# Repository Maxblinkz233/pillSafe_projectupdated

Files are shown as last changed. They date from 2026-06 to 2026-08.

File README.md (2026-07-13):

# PillSafe

Smart medication dispenser (Raspberry Pi hub) + **React Native** caregiver/patient app.

**KNUST — Department of Computer Engineering | BSc Final Year Project**

| Layer | Location | Role |
|---|---|---|
| Pi backend | [`hardware/`](hardware/) | Face/voice verify, schedules, servos, SMS, Flask API |
| Mobile app | [`src/`](src/) | React Native UI wired to the Pi REST API |
| Demo script | [`DEMO.md`](DEMO.md) | Viva / defense walkthrough |

## Quick start — mobile app

```sh
npm install
npm start
# another terminal:
npm run android   # or: npm run ios
```

1. Join the Pi hotspot **PillSafe-AP** (or same LAN).
2. In the app: **Settings → Device Connection**
   - URL: `http://192.168.4.1:5000`
   - Token: from `hardware/config.yaml` → `api.token`
3. **Test Connection** → pick user → **Save**
4. Use **Home / Schedule / Alerts / Verify** against live hub data.

## Quick start — Raspberry Pi hub

Follow the full guide in [`hardware/README.md`](hardware/README.md).

```sh
cd hardware
python3 main.py
# dry-run TAKEN + MISSED for UI proof:
python3 scripts/dry_run_demo.py --db-only
```

## Architecture (app ↔ hub)

- App stores API URL + Bearer token in AsyncStorage.
- **Verify Now** → `POST /dispense/request` with `user_id`, optional `schedule_id`, `auth_mode` (`face` \| `voice`).
- Home / Schedule / Alerts load `/schedules`, `/adherence`, `/notifications`, `/health`.

## Docs

- [Hardware README](hardware/README.md) — wiring, deploy, API reference
- [DEMO.md](DEMO.md) — live demo checklist (taken + missed dose)

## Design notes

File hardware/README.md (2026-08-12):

# PillSafe — Smart Pill Dispenser with Facial Recognition

A Raspberry Pi 5-based smart medication dispensing system that uses facial recognition (FaceNet embeddings), IR-confirmed dispensing, and GSM SMS alerts (SIM800C UART) to ensure safe, verified, and logged medication delivery.

**KNUST — Department of Computer Engineering | BSc Final Year Project**
**Authors:** Boison, Simeon A.A. | Donkor, Maxwell J.
**Supervisor:** Dr Bright Yeboah-Akowuah

---

## Project Structure

```
pillsafe/
│
├── main.py                        # Entry point — initialises and runs everything
├── config.yaml                    # Central configuration (all tuneable parameters)
├── requirements.txt               # Python dependencies
│
├── core/                          # Facial recognition pipeline
│   ├── camera.py                  # Pi Camera v2 capture (Picamera2)
│   ├── detector.py                # Haar Cascade face detection + preprocessing
│   ├── facenet_recogniser.py      # FaceNet embedding-based recognition
│   └── decision.py                # Orchestrates detection → FaceNet recognition
│
├── hardware/                      # Physical component interfaces
│   ├── gpio_compat.py             # Pi 5 lgpio → RPi.GPIO → simulation
│   ├── dispenser.py               # 6× MG996R servos × 9 slots (no gate)
│   ├── ir_sensor.py               # FC-51 IR sensors (pill detect + pickup)
│   ├── buzzer.py                  # 5V active buzzer for audio feedback
│   ├── rtc.py                     # DS3231 RTC via I2C
│   └── gsm.py                     # SIM800C SMS via Pi UART (/dev/serial0)
│
├── scheduler/                     # Time-based dispensing triggers
│   └── schedule_controller.py     # RTC polling + DispenseEvent generation
│
├── database/                      # SQLite data layer
│   ├── schema.sql                 # Tables (Users, Schedules, Inventory, AdherenceLog, Notifications)
│   └── db_manager.py              # Thread-safe CRUD helpers
│
├── api/                           # Flask REST API for mobile app
│   └── routes.py                  # All endpoints (users, schedules, adherence, health)
│
├── alerts/                        # SMS notification service
│   └── alert_service.py           # Background thread monitoring missed-dose events
│
├── enrollment/                    # User facial enrolment
│   └── enrol_user.py              # Sample capture + model retraining (CLI + API)
│
├── utils/                         # Shared utilities
│   ├── config.py                  # YAML config loader with dot-notation access
│   └── logger.py                  # Project-wide logging setup
│
├── data/                          # Runtime data (auto-created)
│   ├── dataset/                   # Facial samples and embeddings: dataset/{user_id}/
│   │                              # embeddings.npy, embeddings_metadata.txt
│   ├── pillsafe.db                # SQLite database
│   └── pillsafe.log               # Application log
│
└── services/
    └── pillsafe.service           # systemd unit file for auto-start on boot
```

---

## Hardware Wiring Guide

> **Full circuit (every wire, resistor, capacitor):** [`docs/WIRING_GUIDE.md`](docs/WIRING_GUIDE.md)  
> **BOM:** [`docs/bom.csv`](docs/bom.csv) · **Net checklist:** [`docs/fritzing_connections.csv`](docs/fritzing_connections.csv)

### GPIO Pin Assignment (BCM Numbering)

| Component | Signal | GPIO (BCM) | Physical Pin | Notes |
|---|---|---|---|---|
| Servo — compartment 0 | PWM | GPIO 12 | Pin 32 | One servo per compartment |
| Servo — compartment 1 | PWM | GPIO 13 | Pin 33 | |
| Servo — compartment 2 | PWM | GPIO 16 | Pin 36 | |
| Servo — compartment 3 | PWM | GPIO 17 | Pin 11 | |
| Servo — compartment 4 | PWM | GPIO 26 | Pin 37 | |
| Servo — compartment 5 | PWM | GPIO 27 | Pin 13 | |
| Servos | VCC | — | External 5V  | MG996R; ≥5–6 A; common GND  |
| Servos | GND | — | GND | Common ground with Pi |
| FC-51 IR (pill det) | OUT | GPIO 23 | Pin 16 | At discharge chute |
| FC-51 IR (pickup) | OUT | GPIO 24 | Pin 18 | At delivery tray |
| FC-51 IR sensors | VCC | — | Pin 1 (3.3V) | Both sensors |
| FC-51 IR sensors | GND | — | Pin 9 | Both sensors |
| Active Buzzer (5V)  | Signal | GPIO 25 | Pin 22 | |
| Active Buzzer (5V)  | VCC | — | Pin 2/4 (5V) | Not 3.3V |
| Active Buzzer | GND | — | Pin 20 | |
| DS3231 RTC | SDA | GPIO 2 | Pin 3 | I2C data (fixed) |
| DS3231 RTC | SCL | GPIO 3 | Pin 5 | I2C clock (fixed) |
| DS3231 RTC | VCC | — | Pin 1 (3.3V) | |
| DS3231 RTC | GND | — | Pin 14 | |
| Pi Camera | CSI | — | CSI port | Ribbon to Pi 5 camera port  |
| SIM800C GSM | TX | GPIO 15 RX | Pin 10 | 3.3V TTL UART |
| SIM800C GSM | RX | GPIO 14 TX | Pin 8 | 3.3V TTL UART |
| SIM800C GSM | VCC | — | — | 3.7–4.2V LiPo (separate) |
| SIM800C GSM | GND | — | Common GND | Share ground with Pi |

### Wiring Diagram (Text)

```
Raspberry Pi 5 GPIO Header (40-pin) — signal pins in BCM numbering
══════════════════════════════════════════════════════════════════
 Power / Ground
   Pin 1  (3.3V) ─── IR VCC, RTC VCC
   Pin 2/4 (5V)  ─── Buzzer VCC (5V module); servos use EXTERNAL 5V ≥5–6 A
   Pin 6/9/14/20/25/30/34/39 (GND) ─── common ground for ALL modules + servo PSU
 Servos (MG996R 360° — one rotating cylinder per compartment)
   GPIO12 (Pin 32) ─── Compartment 0 servo signal
   GPIO13 (Pin 33) ─── Compartment 1 servo signal
   GPIO16 (Pin 36) ─── Compartment 2 servo signal
   GPIO17 (Pin 11) ─── Compartment 3 servo signal
   GPIO26 (Pin 37) ─── Compartment 4 servo signal
   GPIO27 (Pin 13) ─── Compartment 5 servo signal
 Sensors / feedback
   GPIO23 (Pin 16) ─── IR sensor 1 OUT (discharge chute — drop confirm)
   GPIO24 (Pin 18) ─── IR sensor 2 OUT (delivery base — pickup confirm)
   GPIO25 (Pin 22) ─── Buzzer signal (5V module)
 I2C — DS3231 RTC
   GPIO2  (Pin 3, SDA) ─── DS3231 SDA
   GPIO3  (Pin 5, SCL) ─── DS3231 SCL
 UART — SIM800C (3.3V TTL; Serial Console disabled in raspi-config)
   GPIO14 (Pin 8,  TXD0) ─── SIM800C RX
   GPIO15 (Pin 10, RXD0) ─── SIM800C TX
 Voice mic — INMP441 I2S (deferred; leave voice.enabled: false)
 Camera
   CSI port ─── Pi Camera ribbon cable
══════════════════════════════════════════════════════════════════
 SIM800C: powered by a separate 3.7–4.2V LiPo; share GND with the Pi.
 POWER NOTE: six MG996R servos need an external 5V ≥5–6 A supply.
 Tie that supply's GND to a Pi GND — do NOT power 6 servos from the Pi.
```

### Important Notes

1. **SIM800C Power**: Separate 3.7–4.2V LiPo (NOT from Pi rails). Peak TX can approach 2 A.
2. **Common Ground**: SIM800C GND must share ground with the Pi for UART.
3. **Serial Port**: Enable hardware serial, disable login shell. Device: `/dev/serial0`.
4. **I2C Setup**: `sudo raspi-config → Interface Options → I2C → Enable`. Verify with `sudo i2cdetect -y 1`.
5. **Camera**: Enable via `sudo raspi-config → Interface Options → Camera → Enable`.
6. **IR Sensor Orientation**: Mount FC-51 at discharge chute and delivery tray.
7. **Voice**: Leave `voice.enabled: false` until INMP441 is fitted. KY-037 is not suitable for MFCC.

---

## Raspberry Pi 5 — Step-by-Step Deployment

Follow these steps in order once you have the hardware. Commands assume
Raspberry Pi OS **Bookworm 64-bit** and the default username `pi`. If your
username is different, substitute it everywhere (and in
`services/pillsafe.service`). The guide installs into `/home/pi/pillsafe`.

### What you need
- Raspberry Pi 5 + official 27W USB-C PD supply + microSD card (32 GB+)
- Pi Camera (CSI), DS3231 RTC (+ CR2032), 5V active buzzer
- 2× FC-51 IR sensors, 6× MG996R 360° servos + **external 5V ≥5–6 A** supply
- SIM800C GSM on Pi UART (`/dev/serial0`) + 3.7–4.2V LiPo (3.3V TTL)
- (Deferred) INMP441 — keep `voice.enabled: false` until fitted
- Jumper wires / breadboard or a wiring harness

### Step 1 — Flash Raspberry Pi OS
1. Install **Raspberry Pi Imager** on your PC.
2. Choose *Raspberry Pi OS (64-bit)* → your microSD card.
3. Click the gear / *Edit Settings* and pre-configure:
   - Hostname (e.g. `pillsafe`), enable **SSH**, set username `pi` + a password.
   - Wi-Fi SSID/password (so the first boot has internet) and your locale/timezone.
4. Write the card, insert it into the Pi, and boot.

### Step 2 — First boot, update, correct clock
SSH in (`ssh pi@pillsafe.local`) or use a monitor, then:
```bash
sudo apt update && sudo apt full-upgrade -y
timedatectl        # confirm the system time/date is correct (needed to seed the RTC later)
```

### Step 3 — Enable the hardware interfaces
```bash
sudo raspi-config
#  Interface Options → Camera      → Enable
#  Interface Options → I2C         → Enable
#  Interface Options → Serial Port → login shell over serial: NO, serial hardware: YES
```
For the **optional voice mic**, enable I2S by adding this line to
`/boot/firmware/config.txt` (Bookworm path) and reboot:
```bash
echo "dtparam=i2s=on" | sudo tee -a /boot/firmware/config.txt
# Then add the overlay for your INMP441 board per its datasheet, and reboot.
sudo reboot
```

### Step 4 — Install system packages
```bash
sudo apt install -y python3-pip python3-opencv python3-picamera2 \
                    i2c-tools git wget libportaudio2 libsndfile1
```

### Step 5 — Get the PillSafe code onto the Pi
```bash
cd /home/pi
git clone <your-repo-url> pillsafe        # or copy the project folder here via scp
cd /home/pi/pillsafe
```
> If you copy instead of clone, make sure the folder ends up at exactly
> `/home/pi/pillsafe` so it matches the service file in Step 14.

### Step 6 — Install the Python dependencies
```bash
cd /home/pi/pillsafe
pip install -r requirements.txt --break-system-packages

# FaceNet needs a TFLite runtime (ARM64). Try tflite-runtime first;
# fall back to ai-edge-litert if no wheel is available for your Python:
pip install tflite-runtime --break-system-packages || \
pip install ai-edge-litert --break-system-packages
```
> The voice deps (`sounddevice`, `librosa`) are heavy. If you are **not** using
> voice auth, set `voice.enabled: false` in `config.yaml` — the system runs
> fine without them.

### Step 7 — Download the face-recognition model
```bash
bash scripts/download_model.sh          # saves data/models/mobilefacenet.tflite
```

### Step 8 — Wire the hardware and verify each part
Wire everything per the **Hardware Wiring Guide** above (mind the servo power
note). Then verify:
```bash
i2cdetect -y 1          # DS3231 should appear at address 0x68
ls -l /dev/serial0     # SIM800C UART (serial HW on, console off)
libcamera-hello -t 2000 # camera preview (or 'rpicam-hello' on newer OS)
arecord -l              # (voice only) the INMP441 should be listed
```

### Step 9 — Configure `config.yaml`
Edit `config.yaml` and set at minimum:
- `api.token` — replace `CHANGE_ME_ON_FIRST_SETUP` with a strong token (or export
  `PILLSAFE_API_TOKEN` instead; it overrides the file).
- `alerts.serial_port` — `/dev/serial0` for SIM800C UART.
- `servo.pins` — confirm they match how you wired the six MG996R servos.
- `hotspot.ssid` / `hotspot.password` — your access-point name and WPA2 passphrase.
- leave `voice.enabled: false` until INMP441 is fitted.

### Step 10 — Set the DS3231 RTC time
With the system clock correct (Step 2), write it into the RTC once:
```bash
cd /home/pi/pillsafe
python3 -c "from utils.config import load_config; load_config(); \
from hardware.rtc import RealTimeClock; from datetime import datetime; \
print('RTC set:', RealTimeClock().set_time(datetime.now()))"
```
The DS3231's backup cell keeps time across power loss, so schedules fire
correctly even offline.

### Step 11 — (Optional) Turn the Pi into a Wi-Fi hotspot
So a caregiver's phone can connect directly with no router:
```bash
sudo bash services/setup_hotspot.sh
# Phone connects to SSID 'PillSafe-AP'; the API is then at http://192.168.4.1:5000
# To undo:  sudo bash services/setup_hotspot.sh --disable
```

### Step 12 — Enrol users and stock the slots
Register + capture faces (and voice). For a **headless** Pi use the CLI tool;
if a monitor is attached you can use the live-preview tool instead:
```bash
python3 -m enrollment.enrol_user      # headless-friendly
# or, with a screen attached:
python3 enroll_new_user.py            # live camera preview + progress bar
```
Then load the initial pill counts per slot (optional but enables low-stock
alerts) via the API — see Step 15, or POST to `/inventory`.

### Step 13 — Test run (foreground)
```bash
cd /home/pi/pillsafe
python3 main.py
```
Watch the log. In another terminal, confirm the API answers:
```bash
curl http://localhost:5000/health
```
Press `Ctrl+C` to stop once it looks healthy.

### Step 14 — Install as a boot service (auto-start)
```bash
sudo cp services/pillsafe.service /etc/systemd/system/
sudo systemctl daemon-reload
sudo systemctl enable pillsafe      # start automatically on every boot
sudo systemctl start pillsafe
sudo systemctl status pillsafe      # should show 'active (running)'
journalctl -u pillsafe -f           # live logs
```
> If your username isn't `pi`, edit `User=` and the paths in
> `/etc/systemd/system/pillsafe.service`, then `daemon-reload` and restart.

### Step 15 — Auto-start Expo Metro on boot (optional)

If the Pi also hosts the Expo dev server (phone loads the app from the Pi via
Expo Go), install Node **18+** once, copy `pillsafe-expo/` to the Pi, then:

```bash
# One-time: Node 18+ on Bookworm (example — pick your preferred method)
curl -fsSL https://deb.nodesource.com/setup_20.x | sudo -E bash -
sudo apt-get install -y nodejs

# Sync pillsafe-expo to /home/boison08/Documents/pillSafe_projectupdated/pillsafe-expo
cd /home/boison08/Documents/pillSafe_projectupdated/hardware
bash scripts/install_pillsafe_expo_service.sh
```

After reboot both services should be up:

```bash
systemctl is-active pillsafe pillsafe-expo
tail -n 30 data/pillsafe_expo_stdout.log   # QR / exp:// URL appears here
```

On the phone: connect to **PillSafe-AP** (or the same Wi‑Fi), open **Expo Go**,
and enter `exp://10.42.0.1:8081` (hotspot) or `exp://<pi-lan-ip>:8081`.

## Network modes (hotspot ↔ Wi‑Fi from the app)

The Device Connection screen can switch the Pi between **PillSafe-AP** and a
known Wi‑Fi network (no API URL field for end users).

Hub APIs (Bearer auth):

- `GET /network/status`
- `POST /network/hotspot`
- `POST /network/wifi` body `{ "ssid", "password" }`

On the Pi, allow the service user to run `nmcli` without a password:

```bash
sudo bash /home/boison08/Documents/pillSafe_projectupdated/hardware/scripts/install_nmcli_sudoers.sh
sudo systemctl restart pillsafe
```

While on PillSafe-AP the phone uses `http://10.42.0.1:5000` automatically.
After joining home Wi‑Fi, join that same network on the phone and tap **Test Connection**.

## SMS path (Africa’s Talking primary → GSM → phone fallback)

1. Hub calls **Africa’s Talking** REST over HTTPS (credentials in `config.yaml` → `alerts.africas_talking`). Use a **live** username + API key and `sandbox: false` for real caregiver handsets. Sandbox only shows messages in the [AT Simulator](https://simulator.africastalking.com:1517/).
2. If AT fails (missing key, HTTP error, rejected number), hub tries **SIM800L/C** over `/dev/serial0`.
3. If both fail, the hub inserts **`PENDING_PHONE_SMS`** with JSON `{ "to", "body", "reason" }`.
4. The React Native app poller (while connected) sends via phone Africa’s Talking ([`src/config/africasTalking.js`](../src/config/africasTalking.js)) and marks the notification read.

End users only set the caregiver phone (`+233…`). Developers put AT keys in hub `config.yaml` (and optionally the phone config for the last-resort path).

### Deploy SMS after code pull

```bash
# On the Pi — edit live credentials in config.yaml first:
#   alerts.africas_talking.username / api_key, sandbox: false
sudo systemctl restart pillsafe
journalctl -u pillsafe -f
# Expect: "Alert service started (primary=africas_talking, at_configured=True, ...)"
# On a dose event: "Africa's Talking SMS to +233…: Success" (before any pillsafe.gsm line)
```

Pi must have outbound internet (phone hotspot with mobile data, or LAN).

### Step 15 — Connect the mobile app
1. Connect the phone to the Pi's Wi-Fi (`PillSafe-AP`) or the same LAN.
2. Open the **React Native** PillSafe app → **Settings → Device Connection**.
3. Set the API base URL (`http://192.168.4.1:5000` for the hotspot) and the Bearer token from Step 9.
4. Hub SMS uses `hardware/config.yaml` Africa’s Talking keys; optional phone fallback keys live in `src/config/africasTalking.js` (developers only — not shown in the app UI).
5. Tap **Test Connection**, select the patient user, then **Save**.
6. Create users/schedules (API or enrolment CLI), then use **Verify → Verify Now** at dose time.

See [`../DEMO.md`](../DEMO.md) for a full viva/demo checklist, and run a dry-run with:

```bash
python3 scripts/dry_run_demo.py --db-only
# or against a live hub:
python3 scripts/dry_run_demo.py --base-url http://192.168.4.1:5000 --token YOUR_TOKEN
```

### Troubleshooting

| Symptom | Check |
|---|---|
| RTC not found | `i2cdetect -y 1` shows nothing at 0x68 → re-check SDA/SCL/power; is I2C enabled? |
| "TFLite model not loaded" | Run Step 7; confirm `data/models/mobilefacenet.tflite` exists |
| Camera errors | `libcamera-hello`; ensure the CSI ribbon is seated and Camera is enabled |
| No SMS on phone | Set **live** `alerts.africas_talking` (`sandbox: false`); Pi needs HTTPS; caregiver is `+233…`. Sandbox → Simulator only. If AT+GSM fail, hub queues `PENDING_PHONE_SMS` — phone needs data + `src/config/africasTalking.js` |
| GSM-only / no AT | `at_configured=False` in startup log → replace `REPLACE_WITH_*` placeholders; check `journalctl` for Africa's Talking HTTP errors |
| Servos jitter / brown-out | External 5V ≥5–6 A for MG996R; share GND; raise `servo.hold_time` if needed |
| Voice disabled at start | Expected while `voice.enabled: false`; else install sounddevice/librosa + INMP441 |
| Service won't start | `journalctl -u pillsafe -e`; verify `User=`/paths in the unit file |
| API returns 401 | Send `Authorization: Bearer <token>` matching `api.token` / `PILLSAFE_API_TOKEN` |

---

## API Reference

All endpoints (except `/health`) require `Authorization: Bearer <token>` header.

| Method | Endpoint | Description |
|---|---|---|
| GET | /health | System status (no auth) |
| GET | /users | List all users |
| POST | /users | Create user (full_name, caregiver_phone, compartment_index) |
| PUT | /users/{id} | Update user |
| DELETE | /users/{id} | Delete user + facial data |
| POST | /users/{id}/enrol | Trigger facial enrolment |
| GET | /schedules | List schedules (?user_id= filter) |
| POST | /schedules | Create schedule (user_id, medication_name, dose_time, [slot_index, dosage, pills_per_dose, repeat_days]) |
| PUT | /schedules/{id} | Update schedule (incl. slot_index, dosage, pills_per_dose, repeat_days) |
| DELETE | /schedules/{id} | Delete schedule |
| GET | /adherence | Get logs (?user_id=&date= filters) |
| POST | /adherence/{id}/ack | Acknowledge a missed-dose event |
| POST | /dispense/request | "Verify Now" — submit user_id, [schedule_id], auth_mode (face/voice) |
| GET | /inventory | List inventory (?compartment_index= filter)|
| POST | /inventory | Set/update a slot's count (compartment_index, slot_index, pill_count, [medication_name, low_threshold]) |
| GET | /inventory/low | List slots at/below their low threshold |
| GET | /notifications | Event feed (?user_id=&unread=true) |
| POST | /notifications/{id}/read | Mark a notification read |
| GET | /voice/challenge | Random voice passphrase to speak |
| GET | /users/{id}/enrol/status | Face + voice enrolment flags |

> `repeat_days` is a CSV of weekday integers (`0`=Mon … `6`=Sun); empty/omitted means every day. `auth_mode` selects face or voice for that dose.

---

## Medication Storage (Compartments & Slots)

- **6 compartments**, each permanently assigned to one patient (`Users.compartment_index`, 0–5).
- Each compartment is a rotating cylinder with **9 angular slots** (~40° apart). A slot holds one medication / scheduled dose (`Schedules.slot_index`, 0–8).
- Each slot can be **inventory-tracked** (`Inventory` table): a pill count with a low-stock threshold that triggers a `LOW_INVENTORY` notification + SMS.

## Dispensing Mechanism (no gate)

Dispensing is **rotation-only**. Each compartment has its own servo. When a dose is due, that compartment's servo rotates so the target slot aligns with the compartment's fixed **drop hole**; the pill falls by **gravity through a delivery tube to the collection base**. The IR sensors confirm the **drop** and the **pickup**.

## Operational Workflow

```
RTC polls every 60s → Schedule match (time + repeat-day)? → REMINDER notif + buzzer → Camera ON
  → App sends "Verify Now" (POST /dispense/request) → FaceNet/voice verify the SCHEDULED patient
    → ACCEPTED: rotate compartment→slot → IR confirm drop → IR confirm pickup
               → Log TAKEN → decrement inventory → DISPENSED notif (+ LOW_INVENTORY if needed)
    → REJECTED: Log REJECTED → REJECTED notif → SMS to caregiver
    → No Verify Now before grace deadline: Log MISSED → MISSED notif → SMS
```

> Set `dispense.require_verify_request: false` in `config.yaml` for fully autonomous, timer-driven verification (no app handshake).

---

## Key Configuration Parameters

| Parameter | Default | Description |
|---|---|---|
| face.confidence_threshold | 60 | FaceNet match score 0–100 = (1−cosine_dist)×100 (higher = stricter) |
| face.distance_threshold | 0.4 | Max cosine distance (= matches confidence 60) |
| face.max_retries | 8 | Verification attempts before lockout |
| face.sample_count | 50 | Images captured during enrolment |
| schedule.grace_period_minutes | 15 | Window before marking dose as MISSED |
| schedule.poll_interval_seconds  | 60 | How often the scheduler checks the RTC |
| dispense.require_verify_request | true | Wait for the app's "Verify Now" before auth |
| alerts.max_sms_per_event | 2 | Maximum SMS alerts per missed dose |
| alerts.retry_interval_minutes | 60 | Wait time before sending 2nd SMS |
| servo.num_compartments | 6 | Number of compartments (one per patient) |
| servo.num_slots | 9 | Angular slots per compartment (~40° each) |
| servo.pins | [12,13,16,17,26,27] | One PWM signal pin per compartment |

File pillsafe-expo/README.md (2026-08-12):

# PillSafe Expo copy

This is an Expo Go-compatible copy of the existing React Native app. The original
app at the repository root remains unchanged.

The copy intentionally targets **Expo SDK 54**, because the SDK 57 version of
Expo Go is still awaiting Apple App Store approval.

## Run on an iPhone from Windows

1. Install **Expo Go** from the iPhone App Store.
2. Connect the iPhone and Windows PC to the same Wi-Fi network.
3. From this folder, run:

   ```sh
   npm install
   npm start
   ```

4. Scan the displayed QR code with the iPhone camera and open it in Expo Go.
5. In PillSafe, open **Settings → Device Connection** and configure the Pi URL
   and API token.

## SMS (hub Africa’s Talking → GSM → phone fallback)

Hub sends caregiver SMS via **Africa’s Talking** first (live keys in Pi
`config.yaml`). If that fails, GSM; if both fail, the hub queues
`PENDING_PHONE_SMS` and this app’s poller sends via Africa’s Talking using
[`src/config/africasTalking.js`](src/config/africasTalking.js) (developers only —
not in the UI). The phone needs internet for that last-resort API call while
still reaching the hub for polling.

During face enrolment and face verification, the app displays the live
Raspberry Pi camera preview. The preview requires the updated Pi backend in this
repository to be running.

For live hub access, the iPhone, PC running Metro, and Raspberry Pi must be
reachable on the same network. If LAN discovery fails, run `npm start -- --tunnel`;
the iPhone and PC then need internet access, while the iPhone must still be able
to reach the Pi API.

## Auto-start Metro on the Raspberry Pi

You can run Expo on the Pi itself so it starts on every boot (no PC needed):

1. Install **Node.js 18+** on the Pi.
2. Copy this `pillsafe-expo/` folder to
   `/home/boison08/Documents/pillSafe_projectupdated/pillsafe-expo`.
3. On the Pi:

   ```sh
   cd /home/boison08/Documents/pillSafe_projectupdated/hardware
   bash scripts/install_pillsafe_expo_service.sh
   ```

4. Reboot and check:

   ```sh
   systemctl is-active pillsafe-expo
   tail -n 30 /home/boison08/Documents/pillSafe_projectupdated/hardware/data/pillsafe_expo_stdout.log
   ```

5. On the phone (Expo Go): connect to PillSafe-AP or the same Wi‑Fi, then open
   `exp://10.42.0.1:8081` (hotspot) or `exp://<pi-ip>:8081`.

The hub (`pillsafe.service`) and Metro (`pillsafe-expo.service`) are separate
units — enable both for a fully self-contained Pi demo.

## Compatibility note

`react-native-vision-camera` was not copied because the app does not import or
use it. Face and voice verification are initiated by the app but performed by
the Raspberry Pi hub, so removing that unused native dependency does not remove
verification functionality.

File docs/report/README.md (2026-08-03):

# PillSafe FYP Report — Word Paste Pack

Implementation of the *Report vs Implementation — Gap Analysis* plan: Word-ready text that patches Chapter 3 and supplies Chapters 4–6 plus Abstract updates.

## Files

| Order | File | Action in Word |
|---:|---|---|
| 0 | [00_ABSTRACT_AND_FRONT_MATTER.md](00_ABSTRACT_AND_FRONT_MATTER.md) | Replace Abstract; fix “Bright”; extend LoF |
| 1 | [03_CHAPTER3_AMENDMENTS.md](03_CHAPTER3_AMENDMENTS.md) | Amend Ch.3 in place (accuracy pass) |
| 2 | [04_CHAPTER4_IMPLEMENTATION.md](04_CHAPTER4_IMPLEMENTATION.md) | Replace stub Ch.4 |
| 3 | [05_CHAPTER5_TESTING.md](05_CHAPTER5_TESTING.md) | Insert Ch.5; fill measured cells |
| 4 | [06_CHAPTER6_CONCLUSION.md](06_CHAPTER6_CONCLUSION.md) | Insert Ch.6 |

## Source of truth in the repo

- `hardware/config.yaml` — pins, continuous servo, buzzer, SIM800C, grace  
- `hardware/docs/WIRING_GUIDE.md`, `bom.csv` — construction  
- `hardware/api/routes.py` — API surface  
- `src/`, `pillsafe-expo/` — React Native / Expo clients  
- `hardware/cad/` — sized blend / gear–pinion work  

## Writing order (done in this pack)

1. Ch.3 accuracy amendments  
2. Ch.4 implementation narrative  
3. Ch.5 testing tables (ready for your trial numbers)  
4. Ch.6 conclusion + Abstract refresh

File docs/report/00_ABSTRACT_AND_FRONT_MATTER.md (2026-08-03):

# PillSafe — Abstract & Front-Matter Updates

Paste these replacements into the Word report. Do **not** leave the February 2026 draft wording for face-only / Flutter / generic Wi-Fi module.

---

## Abstract (replacement)

Medication non-adherence remains a major cause of treatment failure, especially among elderly and chronically ill patients who manage multiple daily doses. Existing electronic pill dispensers often lack strong identity verification, rely on weak alarms, or do not notify caregivers when a dose is missed. This project presents **PillSafe**, a biometric medication-dispensing system that combines a Raspberry Pi 5 hub with a React Native mobile application.

The hub stores prescribed schedules in SQLite, reminds the patient when a dose becomes due (buzzer on the device and an in-app alert), and releases medication only after successful biometric verification. Authentication uses facial recognition (MobileFaceNet TensorFlow Lite with OpenCV Haar detection) and an optional voice-enrolment / verification path via a Voice HAT microphone. Six patient compartments are driven by MG996R continuous-rotation servos; each compartment holds nine angular slots at 40° steps. After a successful verify, the assigned servo advances one slot and gravity delivers the dose; optional IR sensors can confirm drop and pickup. Missed doses after a configurable grace period, repeated verification failures, and related faults generate SMS alerts to a caregiver through a SIM800C module on the Pi UART. The phone app manages device connection, schedules (including AM/PM dosing and edit/delete), live camera preview for enrolment and verify, adherence monitoring, and the Verify Now handshake with the hub.

The system is designed for home and small-clinic use where reliable, identity-gated dispensing and caregiver visibility matter more than cloud-centric pharmacy automation. Implementation, construction, and evaluation are reported in Chapters 4–6.

**Keywords:** medication adherence, facial recognition, voice biometrics, Raspberry Pi 5, React Native, GSM SMS, smart pill dispenser.

---

## Declaration — supervisor name

Correct the declaration block:

- **Wrong:** … supervised by Mr. Bight …
- **Correct:** … supervised by **Mr. Bright** …

(Use the full official supervisor name as required by your department if it differs from “Bright” alone.)

---

## Suggested list-of-figures additions (Ch.4–6)

| Fig. | Caption (suggested) |
|---|---|
| 4.1 | System stack: Pi 5, Voice HAT, camera, servo rail, SIM800C |
| 4.2 | Power domains (Pi PD / servo 5 V / GSM LiPo) with common GND |
| 4.3 | GPIO pin map used by PillSafe |
| 4.4 | Software module map (hub + mobile app) |
| 4.5 | Enrolment flow (face and optional voice) |
| 4.6 | CAD: compartment outer dimensions (~Ø200 × 21.67 mm) |
| 4.7 | Layer gear (~72T) and matched 16T pinion mesh |
| 5.1–5.n | Face / voice / dispense / reminder / missed-dose result charts |
| 6.1 | Objectives vs achievements summary |

---

## How to use this folder

| File | Purpose |
|---|---|
| `03_CHAPTER3_AMENDMENTS.md` | Accuracy patch for Methodology & Design |
| `04_CHAPTER4_IMPLEMENTATION.md` | New Chapter 4 body |
| `05_CHAPTER5_TESTING.md` | New Chapter 5 body + result tables |
| `06_CHAPTER6_CONCLUSION.md` | New Chapter 6 + future work |
| `00_ABSTRACT_AND_FRONT_MATTER.md` | This file |

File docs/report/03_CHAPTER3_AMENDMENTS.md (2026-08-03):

# Chapter 3 — Methodology & Design: Accuracy Amendments

Replace or amend the corresponding subsections in the existing Chapter 3 so the design chapter matches the **implemented** system. Strike-through / delete obsolete claims (Flutter, Pi 4B as sole target, SG90, 60° six-compartment step, PCA9685 as required PWM driver, SIM800L USB-serial as the only GSM path, face-only auth).

---

## 3.x System overview (amended narrative)

PillSafe consists of:

1. **Hub** — Raspberry **Pi 5** running Python (Flask REST API, schedule controller, face/voice pipelines, dispenser drivers, SQLite).
2. **Mobile client** — **React Native** application (`src/`); an **Expo Go** variant (`pillsafe-expo/`) supports camera-less UI preview during development.
3. **Mechanics** — six patient compartments, each with a rotating cylinder of **nine slots at 40°**, driven by one **MG996R** continuous-rotation servo; gravity drop to a collection point; optional IR confirmation.
4. **Alerts** — on-device **buzzer** when a dose becomes due; **SMS** via **SIM800C** on Pi UART for missed doses, verification failures, and selected faults; in-app reminder poller (“Time Is Up”) on the phone.

Local Wi-Fi (typically the Pi hotspot or LAN) carries HTTPS/HTTP REST between app and hub. No cloud dependency is required for core dispense and adherence logging.

---

## 3.x Hardware platform (replace Pi 4B-centric wording)

| Item | Design choice |
|---|---|
| SBC | **Raspberry Pi 5** (64-bit Raspberry Pi OS) |
| GPIO stack | Compatibility layer: **lgpio** preferred → **RPi.GPIO** fallback → **simulation** for dry-run (`gpio_compat`) |
| Camera | CSI Pi Camera (MJPEG stream + JPEG snapshot to the phone) |
| Voice (optional) | Voice HAT / I2S mic path; sample-rate handling in hub voice modules |
| RTC | DS3231 on I2C for reliable wall-clock scheduling |
| Servos | **6 × MG996R**, continuous / 360° style, external 5 V ≥5–6 A supply, **common GND with Pi** |
| Servo PWM pins | BCM **12, 13, 22, 17, 26, 27** (GPIO **16 avoided** — Voice HAT conflict) |
| IR | FC-51 pair on BCM **23** (drop) and **24** (pickup); may be non-mandatory during bring-up |
| Buzzer | Active module on BCM **25**; **dose-due reminder only** (stopped before dispense verify) |
| GSM | **SIM800C**, UART **`/dev/serial0`** @ 9600; TX→GPIO15(RX), RX→GPIO14(TX); **separate LiPo** power |

**Remove / correct:**

- Claims that the sole controller is Raspberry **Pi 4B**.
- **PCA9685** as a required PWM expander for this pin map (direct GPIO PWM / software PWM as configured).
- Servo on **GPIO18** as the primary dispense pin.
- **SG90** as the project servo.
- **SIM800L over USB-serial** as the documented production path (SIM800C UART is the configured path).

---

## 3.x Dispensing mechanism (replace 60° / single-servo carousel language)

### Compartment geometry

- **Six** patient compartments (one servo each).
- Each cylinder: **nine** dose slots.
- Angular step: **40°** per slot (9 × 40° = 360°).
- Delivery: **gravity drop** after rotation; no motorised gate in the baseline design.

### Actuation model

Continuous-rotation MG996R units are driven with a **timed duty** around a calibrated **neutral** pulse (≈7.5% at 50 Hz), not absolute 0–360° positional PWM.

Key parameters (see `hardware/config.yaml`):

- `mode: continuous`
- `angle_per_slot: 40`
- `neutral_duty`, `run_duty_offset`, `degrees_per_second` — tuned so one command advances ≈ one slot
- `use_slot_indexing: true` — software tracks slot index per compartment

**Remove:** formulas and text that treat the machine as **one** SG90 advancing a shared carousel by **60°** between six compartments.

### Mechanical / CAD design intent

CAD under `hardware/cad/` sizes the stack around a compartment envelope on the order of **~Ø200 mm × ~21.67 mm** height for reference layers. Layer gear work targets approximately **72 teeth** on the large gear with a matched **16-tooth pinion** (pitch radius / centre-distance chosen for mesh with small clearance). Report figures should cite the sized Blender models rather than a generic “carousel sketch.”

---

## 3.x Authentication design (amend face-only sections)

### Face (primary)

- OpenCV Haar cascade for detection.
- **MobileFaceNet** TFLite embeddings; cosine-distance / confidence thresholds from config.
- Enrolment stores samples under the hub dataset path; verify runs on the hub after the app issues Verify Now (when `require_verify_request` is true).
- Live **camera stream** and **snapshot** endpoints support phone-side preview during enrol/verify.

### Voice (optional secondary path)

- Challenge phrase / enrolment APIs (`/voice/challenge`, `/users/<id>/enrol/voice`).
- Verification integrated into the dispense verify path when voice is enabled and enrolled.
- Document Voice HAT sample-rate constraints and that voice may be disabled in config until hardware is fitted.

**Amend** any statement that authentication is **face only**.

---

## 3.x Mobile application (replace Flutter)

| Aspect | Implementation |
|---|---|
| Framework | **React Native** (TypeScript/JavaScript under `src/`) |
| Demo / preview | **Expo Go** project `pillsafe-expo/` for UI without full native camera stack |
| Connection | Device IP + shared API token (`pillsafe` default; change for deployment) |
| Schedules | Create with **AM/PM** dose picker; **long-press** to edit/delete (subject to “already TAKEN today” rules) |
| Reminders | Poller detects due doses; **“Time Is Up”** alert; navigate to Verify via nested `MainApp` → `Verify` |
| Monitor | Missed / adherence aligned with schedule + grace logic used on Home |
| Verify | Disabled when there is no actionable dose; handshake `POST /dispense/request` then hub auth |

**Remove** Flutter/Dart as the implemented client stack.

---

## 3.x Scheduling, reminders, and alerts (amend)

1. Schedules stored in SQLite; hub polls on `poll_interval_seconds` (default 15 s).
2. When a dose becomes due: **buzzer** runs the dose-ready pattern (~45–60 s configurable); buzzer **stops** before dispense authentication so it does not interfere with mic/camera UX.
3. App reminder poller surfaces the same due window; user taps **Verify Now**.
4. Hub authenticates (face ± voice), advances the correct compartment one slot, logs **TAKEN** (IR optional).
5. If grace period expires without success: log **MISSED**, notify caregiver by **SMS** (and in-app notifications where applicable).
6. Repeated failed verify sets can trigger SMS and temporary lockout per face config thresholds.

**Amend** text that treats the buzzer as a generic “start of face verify” alarm only, without the dose-due / stop-before-dispense policy.

---

## 3.x Software architecture sketch (update)

```
React Native app  ──REST──►  Flask API (routes.py)
                                │
                                ├── Face / Voice / Camera
                                ├── ScheduleController
                                ├── Dispenser (6× continuous servo + IR)
                                ├── Buzzer (dose-due)
                                ├── GSM (SIM800C UART)
                                └── SQLite (users, schedules, adherence, …)
```

Central tuning lives in `hardware/config.yaml` (NFR-style single config file).

---

## 3.x API surface (expand the short sketch)

Representative endpoints (all behind shared token / auth as implemented):

| Area | Methods (examples) |
|---|---|
| Health | `GET /health` |
| Camera | `GET /camera/snapshot`, `GET /camera/stream`, `POST /camera/preview/stop` |
| Users | CRUD + `POST .../enrol`, `.../enrol/voice`, `.../enrol/status` |
| Dispense | `POST /dispense/request`, `POST /dispense/verify` |
| Schedules | `GET/POST /schedules`, `PUT/DELETE /schedules/<id>` |
| Adherence | `GET /adherence`, ack endpoints |
| Inventory / notifications | as implemented |
| Test | `POST /alerts/dose-due-test` |

---

## Checklist for the writer (Ch.3 pass)

- [ ] Pi **5** + `gpio_compat` mentioned  
- [ ] React Native (+ Expo Go if used in demo)  
- [ ] Face **and** optional voice  
- [ ] 6 × MG996R, 9 × 40°, continuous timed steps  
- [ ] Pins [12, 13, 22, 17, 26, 27]; no GPIO16 for servo  
- [ ] SIM800C UART `/dev/serial0`  
- [ ] Buzzer = dose-due only; stop before dispense  
- [ ] Flutter / SG90 / 60° / GPIO18-primary / PCA9685-required / face-only removed or clearly marked superseded

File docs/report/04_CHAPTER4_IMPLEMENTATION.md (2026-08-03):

# Chapter 4 — Implementation and Construction

Word-ready body text. Insert figures from photos of your build and from `hardware/cad/` / `hardware/docs/`.

---

## 4.1 Introduction

This chapter describes how the PillSafe design was realised in hardware, embedded software, and the mobile client. It covers the bill of materials and wiring practice, the organisation of hub and app modules, biometric enrolment procedures, and the mechanical CAD decisions that support the six-compartment, nine-slot dispenser.

---

## 4.2 Bill of materials and wiring

### 4.2.1 Bill of materials (summary)

The authoritative parts list is maintained in `hardware/docs/bom.csv`. Major items include:

| Category | Component | Qty | Role |
|---|---|-----|---|
| Controller | Raspberry Pi 5 | 1 | Hub computer |
| Power (Pi) | Official 27 W USB-C PD | 1 | Pi only |
| Storage | microSD 32 GB+ | 1 | Raspberry Pi OS |
| Vision | Pi Camera Module + CSI ribbon | 1 | Enrol / verify |
| Dispensing | MG996R continuous / 360° servo | 6 | One per compartment |
| Dispensing | External 5 V ≥5–6 A PSU | 1 | Servo VCC only |
| Sensors | FC-51 IR modules | 2 | Drop + pickup |
| Feedback | Active 5 V buzzer | 1 | Dose-due reminder |
| Time | DS3231 + CR2032 | 1 | RTC |
| GSM | SIM800C + LiPo + SIM + antenna | 1 set | Caregiver SMS |
| Voice (optional) | Voice HAT / I2S mic | 0–1 | Voice enrol/verify |
| Passives | 1000 µF rail caps, optional PWM series R, TX divider if needed | as BOM | Electrical safety |

Full notes and config cross-references remain in the BOM CSV.

### 4.2.2 Power architecture

Three **isolated positive rails** share a **single common ground**:

1. Pi — official USB-C PD only.  
2. Servos — external 5 V high-current supply (never the Pi 5 V pins for six MG996R).  
3. SIM800C — 3.7–4.2 V LiPo (GSM TX peaks must not collapse the Pi rail).

A bulk electrolytic capacitor (e.g. 1000 µF / 16 V) across the servo rail absorbs stall spikes. Power-up order: wiring complete → GND verified → servo PSU → LiPo → Pi last.

*[Insert Figure 4.2 — power domains diagram; may reproduce the ASCII/schematic from WIRING_GUIDE.md]*

### 4.2.3 Signal wiring summary

Detailed pin-by-pin instructions are in `hardware/docs/WIRING_GUIDE.md`, with a net checklist in `fritzing_connections.csv`.

| Function | BCM / interface | Notes |
|---|---|---|
| Servo PWM | 12, 13, 22, 17, 26, 27 | One line per compartment; GPIO 16 reserved / Voice HAT |
| IR drop / pickup | 23 / 24 | 3.3 V logic |
| Buzzer | 25 | VCC from Pi 5 V if module is 5 V active |
| RTC | I2C (SDA/SCL) | DS3231 @ 0x68 |
| GSM | UART `/dev/serial0` | SIM800C TX→15, RX→14; 3.3 V TTL; divider if TX > 3.3 V |
| Camera | CSI | Stream + snapshot via API |
| Voice | Voice HAT / I2S | As fitted; keep `voice.enabled` false until ready |

GPIO access on Pi 5 uses the project compatibility layer (`hardware/gpio_compat.py`) so the same code path can run under lgpio, RPi.GPIO, or simulation for dry-run demos without hardware.

*[Insert Figure 4.3 — annotated 40-pin header map]*

---

## 4.3 Hub software implementation

### 4.3.1 Module map

| Module / area | Responsibility |
|---|---|
| `main.py` | Process entry, wiring of controllers, API start |
| `config.yaml` | Single source of tuneable thresholds and pins |
| `gpio_compat.py` | Pi 5–friendly GPIO backends |
| `core/` / face pipeline | Haar + MobileFaceNet TFLite match |
| Voice modules | Challenge, enrol, verify (when enabled) |
| Camera helpers | Shared camera for MJPEG / JPEG endpoints |
| `dispenser.py` | Continuous servo slot steps, IR wait policy |
| Schedule controller | Due / grace / MISSED / REMINDER coordination |
| `gsm.py` | SIM800C AT commands over UART |
| Buzzer driver | Dose-due pattern; stopped before dispense |
| `api/routes.py` | Flask REST surface for the phone |
| SQLite DB layer | Users, schedules, adherence, inventory, notifications |

*[Insert Figure 4.4 — module block diagram]*

### 4.3.2 Dispenser control

With `servo.mode: continuous`, a dispense command does not seek an absolute PWM angle. Instead it:

1. Selects the compartment pin for the patient / schedule.  
2. Runs the servo away from `neutral_duty` for a duration derived from `angle_per_slot` and `degrees_per_second`.  
3. Returns to neutral and settles.  
4. Advances the software slot index.  
5. Optionally waits for IR confirmation (`ir_sensors.required`); during bring-up this may be false so TAKEN can still be logged after a successful verify and move.

Calibration consists of adjusting `degrees_per_second` (and duty offsets) until one step visually matches ≈40° on the printed cylinder.

### 4.3.3 Scheduling and reminder policy

- Schedules and adherence events persist in SQLite.  
- The hub polls on a short interval (default 15 s).  
- On dose-due: buzzer pattern (~50 s typical); app may call `POST /alerts/dose-due-test` during lab tests.  
- When `require_verify_request` is true, the hub waits for `POST /dispense/request` from the app before running authentication.  
- After success, dispense runs and adherence is updated; after grace expiry, MISSED + SMS paths fire.

### 4.3.4 REST API (implemented)

The Flask service binds `0.0.0.0:5000` by default with a shared token. Implemented groups include health, camera snapshot/stream, user CRUD and enrolment, voice challenge/enrol, dispense request/verify, schedule CRUD, adherence, inventory, notifications, and dose-due test. This is a full operational surface, not a stub.

---

## 4.4 Mobile application implementation

### 4.4.1 Stack

The production-facing client is **React Native** under `src/`. A parallel **Expo Go** project (`pillsafe-expo/`) allows rapid UI iteration when native camera tooling is not required.

### 4.4.2 Key screens and behaviours

| Feature | Behaviour |
|---|---|
| Device connection | Hub IP + API token; health check |
| Home / dashboard | Today’s doses, adherence-oriented stats |
| Schedules | Create with AM/PM picker; long-press edit/delete; block edit after TAKEN today where enforced |
| Reminders | Background-style poller while app usable; “Time Is Up”; deep link to Verify via nested navigation `MainApp` → `Verify` |
| Verify | Camera preview against hub stream/snapshot; disabled when no actionable dose |
| Monitor | Missed counts aligned with the same schedule + grace logic as Home |
| Enrolment UI | Face (and voice when enabled) against hub enrol endpoints |

---

## 4.5 Enrolment procedures

### 4.5.1 Face enrolment

1. Create or select the patient user on the hub (app or API).  
2. Ensure camera preview is live (`/camera/stream` or snapshot).  
3. Call face enrol (`POST /users/<id>/enrol`) and capture the configured sample count under good lighting.  
4. Confirm enrol status via `/users/<id>/enrol/status`.  
5. Validate with a dry verify before loading medication.

### 4.5.2 Voice enrolment (optional)

1. Enable voice in config and confirm Voice HAT / mic path.  
2. Fetch challenge text (`GET /voice/challenge`).  
3. Record and submit (`POST /users/<id>/enrol/voice`).  
4. Confirm status; include voice in subsequent `/dispense/verify` trials.

*[Insert Figure 4.5 — enrolment sequence diagram]*

---

## 4.6 Mechanical construction and CAD

### 4.6.1 Compartment stack

Sized Blender models under `hardware/cad/` (e.g. `PillSafe_Design_SIZED.blend` and working copies) define a compartment envelope on the order of:

- Outer diameter ≈ **200 mm**  
- Layer / compartment height ≈ **21.67 mm** (reference layer used for stacking)

Six layers correspond to six patients; each layer’s inner cylinder presents **nine** equal sectors for doses.

### 4.6.2 Drive gear and pinion

Layer gear geometry used in the sized design is approximately **72 teeth** at **5°** tooth spacing on the large ring. A matched **16-tooth** stub pinion was designed so that:

- Pitch radii sum (plus a small clearance, e.g. ~0.2 mm) set centre distance.  
- Tip/root diameters and face width suit FDM print tolerance.  
- Material assignment in CAD distinguishes structural plastic from a steel-look pinion for clarity in figures.

*[Insert Figure 4.6 — compartment dimensions]*  
*[Insert Figure 4.7 — 72T ring vs 16T pinion mesh]*

### 4.6.3 Assembly notes

- Print tolerance on tooth thickness and backlash dominates continuous-servo open-loop accuracy; mechanical calibration and `degrees_per_second` must be co-tuned.  
- Gravity drop path and IR sight lines should be verified before locking the outer shell.  
- Keep servo wiring strain-relieved; PWM lines may use optional series resistors per the wiring guide.

---

## 4.7 Configuration and dry-run practice

All tuneables live in `hardware/config.yaml` (face thresholds, grace period, servo continuous calibration, buzzer timing, GSM port, API token). Unit tests and dry-run / simulation paths for dispenser and database support bring-up without full mechanics. Document the token change and serial console disable (`raspi-config`: serial port on, login shell off) as part of commissioning.

---

## 4.8 Chapter summary

PillSafe was implemented as a Pi 5 hub with continuous MG996R slot indexing, Flask APIs including camera and biometrics, SIM800C UART alerts, and a React Native client with schedule and reminder UX. Mechanical CAD progressed from a generic carousel sketch to sized layers with an explicit gear–pinion pair. The next chapter evaluates these subsystems through structured tests.

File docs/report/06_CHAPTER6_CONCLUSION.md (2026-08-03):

# Chapter 6 — Conclusion and Future Work

Word-ready body. Align the objectives checklist with the wording used in Chapter 1 of your dissertation.

---

## 6.1 Conclusion

This project set out to design and implement **PillSafe**, a biometric, schedule-driven medication dispenser for home and small-clinic use. The realised system centres on a **Raspberry Pi 5** hub and a **React Native** mobile application.

On the hub, prescribed times are stored in SQLite and supervised by a schedule controller. When a dose becomes due, the device issues a **buzzer reminder** and the phone can surface a **“Time Is Up”** alert. Medication is released only after successful biometric checks—**facial recognition** with MobileFaceNet TFLite, with an **optional voice** enrolment/verification path. Dispensing uses **six MG996R** continuous-rotation servos, each advancing a **nine-slot** cylinder in **40°** calibrated steps, with gravity delivery and optional IR confirmation. Caregivers can be notified by **SMS** through a **SIM800C** on the Pi UART when doses are missed or verification fails repeatedly.

Relative to the early design draft, the implementation clarified several engineering choices: Pi 5 GPIO compatibility, continuous rather than absolute positional servo control, per-compartment motors instead of a single SG90 carousel step, UART GSM instead of USB-serial SIM800L as the primary path, and React Native instead of Flutter. Mechanical CAD progressed to sized compartment geometry and a matched **~72T / 16T** gear–pinion pair.

Overall, PillSafe demonstrates a coherent end-to-end pipeline—from schedule and reminder, through identity-gated dispense, to adherence logging and caregiver alert—suitable as a final-year prototype and as a foundation for further clinical hardening.

---

## 6.2 Objectives versus achievements

Adapt row wording to match Chapter 1 exactly.

| # | Objective (from Ch.1) | Status | Evidence |
|---|---|---|---|
| 1 | [e.g. Design a multi-compartment dispenser with identity control] | Achieved / Partially | Ch.3–4; 6×9 mechanism; face (± voice) |
| 2 | [e.g. Implement scheduling and dose reminders] | Achieved / Partially | Schedule controller; buzzer; app poller |
| 3 | [e.g. Notify caregiver on missed / failed access] | Achieved / Partially | SIM800C path; DB MISSED; Ch.5 Table 5.6 |
| 4 | [e.g. Provide a mobile interface for management] | Achieved | React Native: connect, schedules, verify, monitor |
| 5 | [e.g. Evaluate system performance] | Achieved / In progress | Ch.5 tables — fill with campaign data |

Mark any objective that depended on unfinished print validation or live SMS as **partially achieved** and explain briefly.

---

## 6.3 Contributions

1. An integrated **Pi 5** hub with config-driven face, schedule, dispense, buzzer, and GSM modules.  
2. A **continuous-servo slot index** model aligned with a nine-slot / 40° mechanical layout.  
3. A **React Native** client with connection token, AM/PM schedules, edit/delete, reminder UX, and verify handshake.  
4. Optional **voice** enrolment APIs and camera streaming for phone-assisted biometrics.  
5. CAD and wiring documentation (BOM, wiring guide, sized gear/pinion) supporting reproducible construction.

---

## 6.4 Limitations

- Open-loop continuous servos without encoders.  
- Reminder reliability when the mobile OS suspends the app.  
- IR and GSM sometimes optional or simulated during lab bring-up.  
- Prototype enclosure / full six-layer print validation may still be incomplete.  
- Not a certified medical device; no clinical trial was conducted within this FYP scope.

---

## 6.5 Future work

1. **Push notifications** (FCM/APNs) so caregivers and patients are alerted when the app is backgrounded.  
2. **Full six-layer print and soak test** — multi-day adherence run with all compartments loaded.  
3. **Closed-loop slot indexing** — magnetic encoder or limit switch per cylinder to eliminate drift.  
4. **Optional cloud sync** — encrypted backup of schedules and adherence for multi-caregiver access.  
5. **Clinical usability study** — elderly users and caregivers; measure adherence lift vs manual organisers.  
6. Hardening: rotated API tokens, TLS on the local API, tamper detection on the enclosure.

---

## 6.6 Final remarks

PillSafe shows that commodity SBC hardware, careful GPIO and power design, and a focused mobile client can deliver identity-gated dispensing with caregiver visibility. Completing the measured test campaign in Chapter 5 and refreshing the abstract to match this architecture leaves the dissertation aligned with the working prototype.

---

## After inserting Chapters 4–6

1. Replace the Abstract using `00_ABSTRACT_AND_FRONT_MATTER.md`.  
2. Fix supervisor spelling (**Bright**).  
3. Regenerate **Table of Contents**, **List of Figures**, and **List of Tables**.  
4. Add new references if you cite MobileFaceNet, Expo, lgpio, SIM800C datasheets, etc., not already in Ch.2.  
5. Delete the duplicated stub “4.1 Introduction” that merely recopied Chapter 3’s opening from the February draft.

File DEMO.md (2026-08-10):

# PillSafe — Demo Script (defense / viva)

Use this checklist for a live demonstration. Time budget: ~10–15 minutes.

## Before you start (5 min)

1. Power the Raspberry Pi and external 5 V servo supply (common GND).
2. Confirm service is running:
   ```bash
   sudo systemctl status pillsafe
   # or: cd /home/pi/pillsafe/hardware && python3 main.py
   ```
3. Phone joins **PillSafe-AP** (or same LAN as the Pi).
4. Open the React Native app → **Settings → Device Connection**:
   - API URL: `http://192.168.4.1:5000` (hotspot) or `http://<pi-ip>:5000`
   - Token: value from `hardware/config.yaml` → `api.token`
   - Tap **Test Connection** → select the demo user → **Save**
   - (Developers) Hub SMS: live Africa’s Talking keys in `hardware/config.yaml` → `alerts.africas_talking`. Phone last-resort key: `src/config/africasTalking.js` (not in the UI)
5. Optional dry-run seed (dev machine or Pi):
   ```bash
   cd hardware
   python3 scripts/dry_run_demo.py --db-only
   ```

## Demo A — Successful dose (TAKEN)

| Step | Action | Expected |
|---|---|---|
| 1 | Show **Home** | Live schedules, device Online, stats from API |
| 2 | Wait for RTC schedule match (or create a schedule for *now* + 1 min) | Buzzer `dose_ready`, REMINDER notification |
| 3 | Open **Verify** → **Verify Now (Face)** | App POSTs `/dispense/request` |
| 4 | Enrolled patient faces Pi camera | FaceNet ACCEPT → servo rotates → IR drop → pickup |
| 5 | Show **Home / Alerts** | DISPENSED notification, adherence TAKEN |

**Voice variant:** Verify → Use Voice Instead → speak passphrase into hub mic.

## Demo B — Missed dose (MISSED + SMS)

| Step | Action | Expected |
|---|---|---|
| 1 | Trigger a schedule; do **not** press Verify Now | Grace period (default 15 min — shorten in `config.yaml` for demos) |
| 2 | Let grace expire | Adherence MISSED, MISSED notification |
| 3 | Caregiver phone | SMS via Africa’s Talking first, then SIM800L if AT fails |
| 4 | Show **Alerts** filter **Missed** | Unread MISSED card |

**Shortcut for UI-only proof** (no waiting):

```bash
python3 scripts/dry_run_demo.py --db-only
```

Then refresh Home / Alerts on the phone.

## Demo C — Rejected identity (optional)

1. Start a dose for patient A.
2. Have patient B (or an unenrolled face) attempt verification.
3. After max retries → REJECTED log + SMS + Alerts card.

## Talking points

- Identity is bound to the **scheduled** user (not any enrolled face).
- App does not capture biometrics; the **Pi camera / mic** does.
- Offline-capable: hotspot + SQLite + DS3231 RTC.
- Dual auth: face **or** voice (`auth_mode` on `/dispense/request`).

## Failures & recovery

| Symptom | Fix |
|---|-----|
| App offline / connection error | Device Connection URL/token; same Wi-Fi; `curl http://PI:5000/health` |
| 401 Invalid token | Match `api.token` / `PILLSAFE_API_TOKEN` |
| Verify accepted but no dispense | Check Pi logs: face reject, IR timeout, servo power |
| No SMS | Live AT keys in `config.yaml` (`sandbox: false`), Pi HTTPS; else SIM800L LiPo + `alerts.serial_port`; else `PENDING_PHONE_SMS` + phone data |

## Backup (if hardware fails on the day)

1. Run `python3 scripts/dry_run_demo.py --db-only` and show live app screens.
2. Play a pre-recorded video of a successful physical dispense.
3. Walk examiners through `hardware/main.py` dispense flow and `DEMO.md`.

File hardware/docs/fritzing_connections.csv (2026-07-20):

Net | From | From pin/signal | To | To pin/signal | Wire colour (suggested) | Notes
GND | Pi | Pin 6/9/14/20 GND | GND bus | Common | Black | Star ground for all supplies
GND | External 5V PSU | GND | GND bus | Common | Black | Mandatory — share with Pi
GND | LiPo 3.7V | − | GND bus | Common | Black | SIM800C return path
GND | GND bus | Common | Servo 0 | GND | Brown | Repeat for servos 1–5
GND | GND bus | Common | Servo 1 | GND | Brown
GND | GND bus | Common | Servo 2 | GND | Brown
GND | GND bus | Common | Servo 3 | GND | Brown
GND | GND bus | Common | Servo 4 | GND | Brown
GND | GND bus | Common | Servo 5 | GND | Brown
GND | GND bus | Common | DS3231 | GND | Black
GND | GND bus | Common | IR drop | GND | Black | FC-51 chute
GND | GND bus | Common | IR pickup | GND | Black | FC-51 tray
GND | GND bus | Common | Buzzer | GND | Black | 5V active module
GND | GND bus | Common | SIM800C | GND | Black
GND | GND bus | Common | INMP441 | GND | Black | Optional voice
GND | GND bus | Common | Divider R2 | bottom | Black | Only if SIM TX level-shifted
3V3 | Pi | Pin 1 (3.3V) | DS3231 | VCC | Red | Module usually has 4.7k I2C pull-ups
3V3 | Pi | Pin 1 (3.3V) | IR drop | VCC | Red
3V3 | Pi | Pin 1 (3.3V) | IR pickup | VCC | Red
3V3 | Pi | Pin 1 (3.3V) | INMP441 | VDD | Red | Optional; L/R also to GND
5V_PI | Pi | Pin 2 or 4 (5V) | Buzzer | VCC | Red | 5V buzzer only — not servos/GSM
5V_SERVO | External PSU | +5V | Servo 0 | VCC | Red | Do NOT use Pi 5V for 6× MG996R
5V_SERVO | External PSU | +5V | Servo 1 | VCC | Red
5V_SERVO | External PSU | +5V | Servo 2 | VCC | Red
5V_SERVO | External PSU | +5V | Servo 3 | VCC | Red
5V_SERVO | External PSU | +5V | Servo 4 | VCC | Red
5V_SERVO | External PSU | +5V | Servo 5 | VCC | Red
5V_SERVO_CAP | External PSU | +5V | Cap 1000uF 16V | + | Red | Decoupling near servos
5V_SERVO_CAP | GND bus | Common | Cap 1000uF 16V | − | Black
SERVO0_SIG | Pi | GPIO12 Pin32 | R220_0 | in | Orange | Optional series 220–470Ω
SERVO0_SIG | R220_0 | out | Servo 0 | Signal | Orange | Compartment 0
SERVO1_SIG | Pi | GPIO13 Pin33 | R220_1 | in | Orange
SERVO1_SIG | R220_1 | out | Servo 1 | Signal | Orange | Compartment 1
SERVO2_SIG | Pi | GPIO16 Pin36 | R220_2 | in | Orange
SERVO2_SIG | R220_2 | out | Servo 2 | Signal | Orange | Compartment 2
SERVO3_SIG | Pi | GPIO17 Pin11 | R220_3 | in | Orange
SERVO3_SIG | R220_3 | out | Servo 3 | Signal | Orange | Compartment 3
SERVO4_SIG | Pi | GPIO26 Pin37 | R220_4 | in | Orange
SERVO4_SIG | R220_4 | out | Servo 4 | Signal | Orange | Compartment 4
SERVO5_SIG | Pi | GPIO27 Pin13 | R220_5 | in | Orange
SERVO5_SIG | R220_5 | out | Servo 5 | Signal | Orange | Compartment 5
IR_DROP | IR drop | OUT | Pi | GPIO23 Pin16 | Yellow | LOW = pill in chute
IR_PICKUP | IR pickup | OUT | Pi | GPIO24 Pin18 | Yellow | HIGH = pill removed (per code)
BUZZER | Pi | GPIO25 Pin22 | Buzzer | Signal | Green | 5V active module
I2C_SDA | Pi | GPIO2 Pin3 | DS3231 | SDA | Blue
I2C_SCL | Pi | GPIO3 Pin5 | DS3231 | SCL | Purple
UART_TX | Pi | GPIO14 Pin8 TX | SIM800C | RX | Grey | Pi 3.3V TX → module RX
UART_RX | SIM800C | TX | R1 10k | in | Grey | Skip divider if TX already ≤3.3V
UART_RX | R1 10k | out | Pi | GPIO15 Pin10 RX | Grey | Tap to R2
UART_RX | R1/R2 junction | — | R2 20k | top | Grey
UART_RX | R2 20k | bottom | GND bus | Common | Black
3V7_GSM | LiPo 3.7V | + | SIM800C | VCC | Red | Peak ~2A — not from Pi
3V7_CAP | LiPo 3.7V | + | Cap 1000uF 10V | + | Red | If not onboard SIM module
3V7_CAP | GND bus | Common | Cap 1000uF 10V | − | Black
CSI | Pi Camera | CSI flex | Pi | CSI/CAM port | — | Ribbon — not breadboard
I2S_BCLK | Pi | GPIO18 | INMP441 | SCK | Yellow | Optional voice
I2S_LRCLK | Pi | GPIO19 | INMP441 | WS | Yellow | Optional voice
I2S_DATA | INMP441 | SD | Pi | GPIO20 | Yellow | Optional voice
I2S_LR | INMP441 | L/R | GND bus | Common | Black | Left channel select

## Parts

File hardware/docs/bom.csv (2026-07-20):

Category | Component | Quantity | Notes | Config reference
Controller | Raspberry Pi 5 | 1 | Main computer — use lgpio GPIO backend | main.py / hardware/gpio_compat.py
Power (Pi) | Official Raspberry Pi 27W USB-C PD PSU | 1 | Powers Pi only
Storage | microSD card 32GB+ | 1 | Raspberry Pi OS Bookworm 64-bit
Vision | Pi Camera Module (CSI 5MP or Camera Module 3) | 1 | CSI ribbon to Pi 5 camera connector | core/camera.py
Vision | CSI ribbon cable | 1 | Usually bundled with camera
Dispensing | MG996R continuous-rotation / 360° servo | 6 | One per compartment | servo.pins
Dispensing | External 5V ≥5–6 A PSU | 1 | Servo VCC only — share GND with Pi | servo.*
Dispensing | Rotating cylinder (9 slots) | 6 | Mechanical — per patient
Dispensing | Delivery tube + collection tray | 1 | Mechanical — gravity drop (no gate)
Sensors | FC-51 IR obstacle sensor | 2 | Drop chute + pickup base | ir_sensors.*
Feedback | Active buzzer module 5V | 1 | Signal GPIO 25; VCC → 5V (not 3.3V) | buzzer.pin
Timekeeping | DS3231 RTC module (I2C) | 1 | Address 0x68 | rtc.*
Timekeeping | CR2032 coin cell | 1 | RTC backup battery
GSM | SIM800C module | 1 | SMS alerts via Pi UART | hardware/gsm.py
GSM | 3.7–4.2V LiPo 1000mAh+ | 1 | Separate SIM800C power only
GSM | Nano SIM (active SMS) | 1 | Mobile network
GSM | GSM antenna | 1 | Usually on SIM800C board
Voice (deferred) | INMP441 I2S microphone | 0–1 | Leave voice.enabled: false until fitted | voice.* / hardware.i2s_mic
Wiring | Dupont jumper wires M-F | 40+ | Pi GPIO to modules
Wiring | Dupont jumper wires M-M | 20+ | Breadboard links
Wiring | Breadboard or perfboard | 1-2 | Prototyping
Wiring | GND bus / terminal block | 1 | Common ground for all supplies
Passives | Electrolytic capacitor 1000µF 16V | 1 | Across external 5V servo rail | docs/WIRING_GUIDE.md
Passives | Electrolytic capacitor 1000µF 10V | 0–1 | Across SIM800C VCC if not onboard | docs/WIRING_GUIDE.md
Passives | Series resistor 220–470Ω | 0–6 | Optional on each servo PWM line | docs/WIRING_GUIDE.md
Passives | Resistor 10kΩ + 20kΩ | 0–1 pair | SIM800C TX→Pi RX divider only if TX>3.3V | docs/WIRING_GUIDE.md
Passives | Resistor 4.7kΩ | 0–2 | I2C pull-ups only for bare DS3231 IC | docs/WIRING_GUIDE.md
Passives | Hook-up wire 18–22 AWG | 1 spool | Thick +5V/GND for servo rail

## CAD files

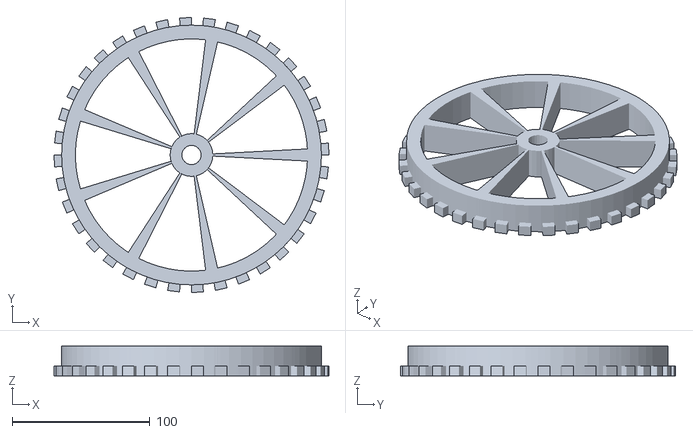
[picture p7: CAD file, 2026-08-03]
hardware/cad/printable/stl/compartment_ref_sized.stl
200.0 x 200.0 x 21.7

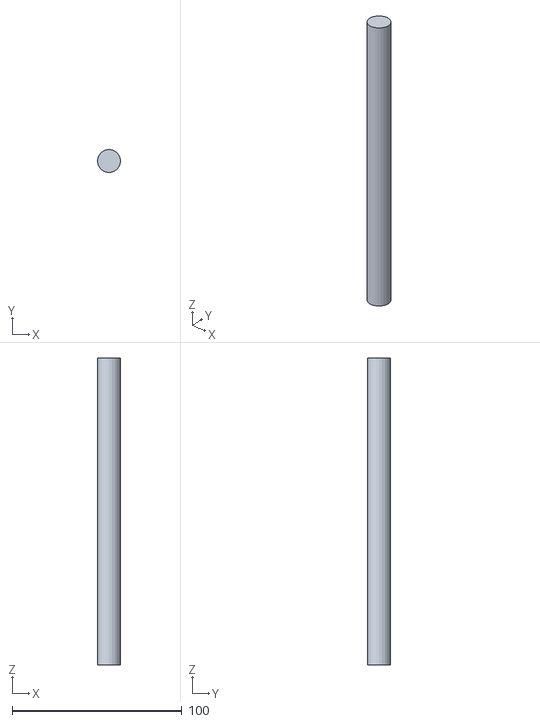
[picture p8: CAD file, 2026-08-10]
hardware/cad/updated rod.stl
13.6 x 13.6 x 180.9

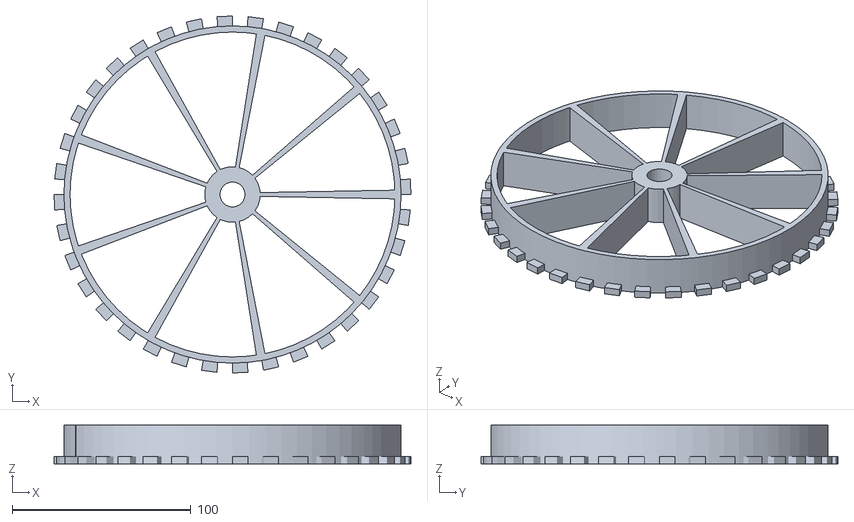
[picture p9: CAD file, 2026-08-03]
hardware/cad/Compartment updated.stl
200.0 x 200.0 x 21.7

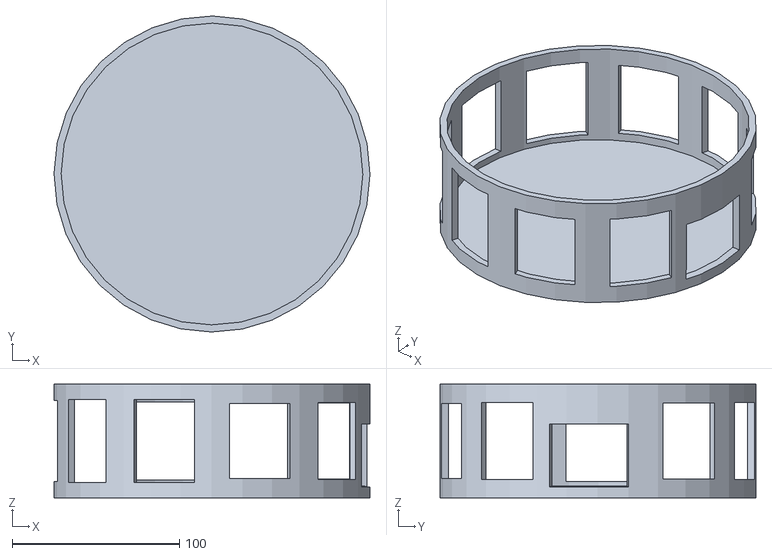
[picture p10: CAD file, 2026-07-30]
hardware/cad/Updated pillsafe base.stl
188.9 x 188.9 x 68.0

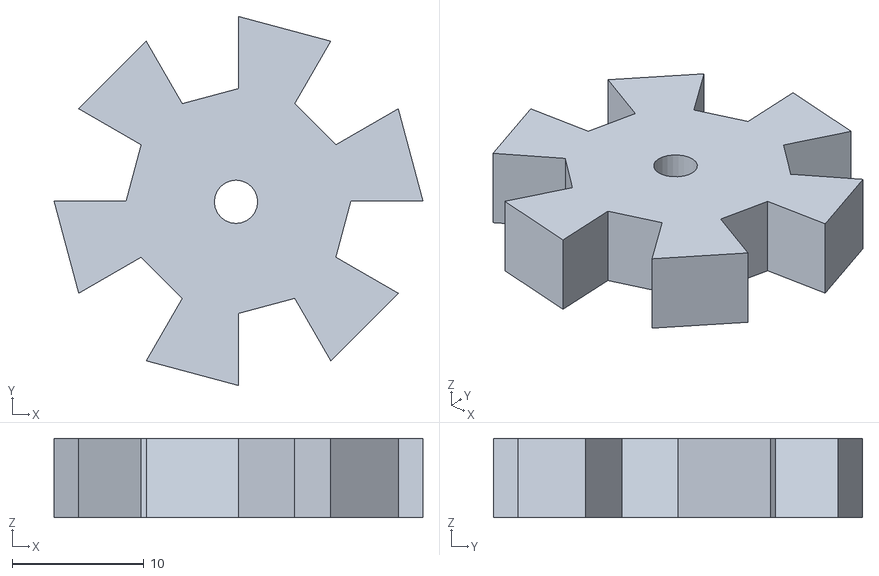
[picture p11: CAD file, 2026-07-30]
hardware/cad/Updated servogear.stl
28.0 x 28.0 x 6.00

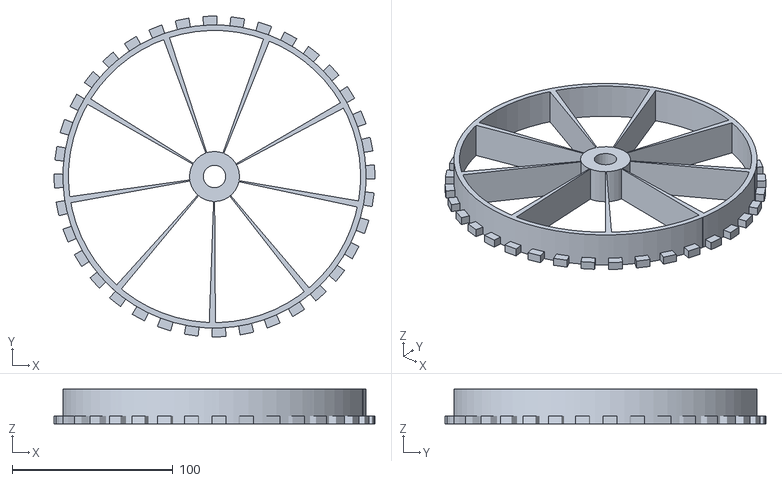
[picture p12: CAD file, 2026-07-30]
hardware/cad/Updated compartment.stl
200.0 x 200.0 x 21.7

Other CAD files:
hardware/PillSafe_Design_SIZED.blend
hardware/cad/PillSafe_Design.blend
hardware/cad/PillSafe_Design_SIZED.blend
hardware/cad/PillSafe_Design_SIZED_copy.blend

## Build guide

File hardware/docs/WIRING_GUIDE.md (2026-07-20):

# PillSafe — Full Hardware Wiring Guide (Raspberry Pi 5)

Complete electrical connection instructions for every device in the hub:
power supplies, Pi GPIO, servos, IR sensors, buzzer, RTC, camera, SIM800C,
optional mic, and the **passive parts** (resistors, capacitors) required for a
safe build.

Matches `config.yaml`, `docs/bom.csv`, and the drivers under `hardware/`.

**Companion files**

| File | Purpose |
|---|---|
| [`bom.csv`](bom.csv) | Parts list |
| [`fritzing_connections.csv`](fritzing_connections.csv) | Net-by-net checklist |
| [`FRITZING_GUIDE.md`](FRITZING_GUIDE.md) | Drawing the circuit in Fritzing |

---

## 0. Safety rules (read before wiring)

1. **Three separate power domains** — never share “+” rails across them:
   - Pi: official **27 W USB-C PD** only
   - Servos: external **5 V ≥ 5–6 A** only
   - SIM800C: **3.7–4.2 V LiPo** only
2. **One common ground** — every supply’s GND must join a single GND bus that
   also ties to Pi GND. Without this, UART/GPIO signals float and damage GPIO.
3. **Pi GPIO is 3.3 V only** — never feed 5 V into a GPIO input pin.
4. **Do not power six MG996R from the Pi 5 V pins** — brown-outs and SD
   corruption are likely.
5. Power-up order: connect all wires → common GND verified → servo PSU →
   LiPo (GSM) → Pi USB-C last.

---

## 1. Power architecture (full picture)

```
                    ┌─────────────────────────────────────────┐
  Mains ───────────►│ Official Pi 5 27W USB-C PD              │──► Pi 5 only
                    └─────────────────────────────────────────┘

                    ┌─────────────────────────────────────────┐
  Mains ───────────►│ External 5V PSU  (≥5–6 A, regulated)    │──► 6× MG996R VCC
                    │   +5V rail                              │
                    │   GND ──────────────────────────────────┼──┐
                    └─────────────────────────────────────────┘  │
                                                                 │
                    ┌─────────────────────────────────────────┐  │
  LiPo 3.7–4.2V ───►│ SIM800C VCC (+), antenna, SIM           │  │
                    │   GND ──────────────────────────────────┼──┤
                    └─────────────────────────────────────────┘  │
                                                                 │
                    ┌─────────────────────────────────────────┐  │
                    │ COMMON GND BUS (terminal block)         │◄─┘
                    │   • Pi GND (pins 6,9,14,20,25,30,34,39) │
                    │   • All module GNDs                     │
                    │   • Servo PSU GND + LiPo GND            │
                    └─────────────────────────────────────────┘

  Pi 3.3V (Pin 1) ──► DS3231 VCC, both FC-51 VCC, (optional INMP441 VDD)
  Pi 5V   (Pin 2/4) ► 5V active buzzer VCC only (not servos, not GSM)
```

### Recommended passive parts on the power rails

| Part | Value | Where | Why |
|---|---|---|-----|
| Electrolytic capacitor | **1000 µF / 16 V** | Across external 5 V servo rail (+ to GND), near servo connectors | Absorbs MG996R stall spikes |
| Ceramic capacitor | **100 nF** | Across servo rail near each servo cluster (optional) | High-frequency noise |
| Electrolytic capacitor | **1000 µF / 10 V** (or module onboard) | Across SIM800C VCC–GND, close to module | GSM TX current bursts (~2 A) |
| Fuse / polyfuse (optional) | **5–7 A** | In series with external 5 V + | Protects wiring on short |
| Terminal block | 2–3 position | Common GND + 5 V rail distribution | Clean star grounding |

---

## 2. Raspberry Pi 5 — 40-pin header map (used pins)

Odd pins left column, even pins right (looking at the Pi with USB ports down;
confirm against the silkscreen on your board).

| Physical pin | Function | Connected to |
|---:|---|---|
| 1 | 3.3 V | DS3231 VCC, IR#1 VCC, IR#2 VCC, (INMP441 VDD) |
| 2 | 5 V | Active buzzer VCC |
| 3 | GPIO 2 (SDA1) | DS3231 SDA |
| 4 | 5 V | Spare / alternate buzzer VCC |
| 5 | GPIO 3 (SCL1) | DS3231 SCL |
| 6 | GND | Common GND bus |
| 8 | GPIO 14 (TXD0) | SIM800C **RX** (after level care — §7) |
| 9 | GND | IR sensors GND |
| 10 | GPIO 15 (RXD0) | SIM800C **TX** (via divider if 5 V — §7) |
| 11 | GPIO 17 | Servo compartment 3 signal |
| 13 | GPIO 27 | Servo compartment 5 signal |
| 14 | GND | DS3231 GND |
| 16 | GPIO 23 | IR drop (chute) OUT |
| 18 | GPIO 24 | IR pickup (tray) OUT |
| 20 | GND | Buzzer GND |
| 22 | GPIO 25 | Buzzer signal |
| 32 | GPIO 12 | Servo compartment 0 signal |
| 33 | GPIO 13 | Servo compartment 1 signal |
| 36 | GPIO 16 | Servo compartment 2 signal |
| 37 | GPIO 26 | Servo compartment 4 signal |
| CSI | Camera connector | Pi Camera ribbon |

Unused for Phase 1 (leave free): GPIO 18/19/20 reserved for optional INMP441.

---

## 3. Component-by-component wiring

### 3.1 Pi Camera (CSI)

| From | To | Notes |
|---|----|---|
| Camera ribbon (contacts toward HDMI side on Pi 5 — check board silkscreen) | Pi 5 **CAM/DISP** port | Power off while inserting |
| — | — | No breadboard wires; enable Camera in `raspi-config` |

Mechanical only after electrical: mount camera facing the user at dose time.

---

### 3.2 DS3231 RTC (I2C)

Modules almost always include **4.7 kΩ pull-ups** on SDA/SCL and a battery holder.

| DS3231 pin | Goes to | Wire |
|---|---|---|
| VCC | Pi Pin 1 (3.3 V) | Red |
| GND | Pi Pin 14 (GND) → common GND | Black |
| SDA | Pi Pin 3 (GPIO 2) | Blue |
| SCL | Pi Pin 5 (GPIO 3) | Purple |
| BAT / CR2032 | Insert CR2032 in holder | Keeps time when Pi is off |

**Extra resistors:** none if the module has onboard pull-ups (typical).  
If you use a bare DS3231 IC (no module): add **2× 4.7 kΩ** from SDA→3.3 V and SCL→3.3 V.

Verify: `sudo i2cdetect -y 1` → device at **0x68**.

---

### 3.3 FC-51 IR obstacle sensors × 2

Each FC-51 board has onboard IR LED + phototransistor + comparator +
**trim pot**; no external resistors required for the standard 3-pin module.

| Sensor | Module pin | Pi / rail | Physical |
|---|---|---|---|
| **IR #1 Drop** (chute) | VCC | 3.3 V | Pin 1 |
| | GND | GND | Pin 9 |
| | OUT | GPIO 23 | Pin 16 |
| **IR #2 Pickup** (tray) | VCC | 3.3 V | Pin 1 (shared rail) |
| | GND | GND | Pin 9 (shared) |
| | OUT | GPIO 24 | Pin 18 |

**Software expectation** (`ir_sensor.py`):

- Drop: OUT goes **LOW** when a pill interrupts the beam.
- Pickup: OUT goes **HIGH** when the pill is removed from the tray (adjust pot / mount so this matches your mechanical layout).

**Optional:** if OUT is open-collector on your clone, add a **10 kΩ pull-up** from OUT to 3.3 V. Most FC-51 boards already drive HIGH/LOW.

Mount:

1. IR #1 across the **delivery tube / chute** after the drop hole.
2. IR #2 at the **collection tray** so presence/absence is reliable.

---

### 3.4 Active 5 V buzzer module

Use a **transistor-buffered active buzzer module** (3 pins: VCC, GND, I/O).  
Do **not** wire a bare piezo across a GPIO pin.

| Buzzer pin | Goes to | Physical |
|---|---|---|
| VCC | Pi **5 V** | Pin 2 or 4 |
| GND | GND | Pin 20 |
| I/O / Signal | GPIO 25 | Pin 22 |

**Resistors:** none for a proper module (driver transistor + base resistor onboard).  
If you only have a bare active buzzer + NPN:

| Part | Value | Connection |
|---|---|---|
| Base resistor | **1 kΩ** | GPIO 25 → base of NPN |
| NPN (e.g. 2N2222) | — | Collector → buzzer − ; emitter → GND |
| Buzzer + | — | Pi 5 V |
| Flyback (if magnetic) | **1N4148** | Across buzzer, cathode to +5 V |

---

### 3.5 MG996R servos × 6 (one per compartment)

Each servo has three wires (typical colour):

| Wire | Function |
|---|---|
| Red | VCC → **external 5 V only** |
| Brown/Black | GND → **common GND** |
| Orange/Yellow | Signal (PWM) → Pi GPIO |

| Compartment | Signal BCM | Physical pin | External |
|---|---|---|---|
| 0 | GPIO 12 | 32 | VCC→5 V PSU, GND→bus |
| 1 | GPIO 13 | 33 | same |
| 2 | GPIO 16 | 36 | same |
| 3 | GPIO 17 | 11 | same |
| 4 | GPIO 26 | 37 | same |
| 5 | GPIO 27 | 13 | same |

**Recommended series resistors on PWM (signal protection):**

| Part | Value | Connection |
|---|---|---|
| 6× series resistors | **220 Ω – 470 Ω** | Each Pi PWM pin → corresponding servo Signal |

These limit fault current if a servo shorts internally. Optional but recommended.

**Decoupling:** 1000 µF on the 5 V rail (§1). Star-wire thick (18–22 AWG) +5 V/GND to all six servos; thin Dupont only for Signal.

**Mechanical:** each servo turns a 9-slot cylinder (~40°/slot). No gate servo — gravity drop only.

---

### 3.6 SIM800C GSM (UART + separate LiPo)

**Enable first (software):**  
`raspi-config` → Interface Options → Serial Port →  
login shell: **No** → serial hardware: **Yes** → reboot.  
Device: `/dev/serial0` (see `alerts.serial_port` in `config.yaml`).

| SIM800C | Goes to | Notes |
|---|---|---|
| VCC / VBAT | LiPo **+** (3.7–4.2 V) | Capable of ~2 A peaks |
| GND | Common GND + LiPo − | Mandatory shared ground |
| TX | Pi GPIO 15 (RX) Pin 10 | **Level-shift if TX is 5 V** — see below |
| RX | Pi GPIO 14 (TX) Pin 8 | Pi 3.3 V TX is usually OK for SIM800C RX |
| Antenna | SMA / u.FL antenna | Fit before SMS tests |
| SIM | Nano SIM (SMS plan) | Insert before powering module |

#### UART resistors — voltage divider on SIM800C TX → Pi RX

Many SIM800C breakouts output **~2.8–3.0 V** on TX (safe). Some clones label
logic as 5 V. **Measure TX idle voltage with a multimeter** before connecting
to the Pi.

If TX ≥ **3.6 V**, add a divider:

```
SIM800C TX ───[ R1 = 10 kΩ ]───┬─── Pi GPIO 15 (RX) / Pin 10
                               │
                              [ R2 = 20 kΩ ]
                               │
                              GND
```

| Part | Value | Role |
|---|---|---|
| R1 | **10 kΩ** | Series from SIM TX |
| R2 | **20 kΩ** | To GND; Vout ≈ Vin × 2/3 |

Alternative pair: **1 kΩ + 2 kΩ** (same ratio, lower impedance).

**Pi TX → SIM RX:** usually direct. If your module requires 5 V logic on RX,
use a bidirectional level shifter (not a bare resistor). Prefer a **3.3 V TTL**
SIM800C board.

**Capacitor:** 1000 µF across SIM VCC–GND if not already on the breakout.

**Do not** power SIM800C from Pi 5 V or 3.3 V alone.

---

### 3.7 Optional — INMP441 I2S mic (voice deferred)

Leave `voice.enabled: false` and `hardware.i2s_mic.enabled: false` until fitted.

| INMP441 | Pi | Notes |
|---|-----|---|
| VDD | 3.3 V (Pin 1) | Not 5 V |
| GND | GND | |
| L/R | GND | Left channel |
| SCK | GPIO 18 | I2S BCLK |
| WS | GPIO 19 | I2S LRCLK |
| SD | GPIO 20 | I2S data |

No external resistors required for the typical breakout.

---

## 4. Full circuit netlist (every connection)

Use this as a wire-by-wire checklist. Suggested colours match
`fritzing_connections.csv`.

### Ground (all black / brown → common GND bus)

| # | From | To |
|---|---|----|
| G1 | Pi Pins 6, 9, 14, 20 (any/all used) | GND bus |
| G2 | External 5 V PSU GND | GND bus |
| G3 | LiPo − | GND bus |
| G4–G9 | Servo 0…5 GND | GND bus |
| G10 | DS3231 GND | GND bus |
| G11–G12 | IR#1 GND, IR#2 GND | GND bus |
| G13 | Buzzer GND | GND bus |
| G14 | SIM800C GND | GND bus |
| G15 | (opt) INMP441 GND | GND bus |
| G16 | (opt) Divider R2 bottom | GND bus |

### +3.3 V (red from Pi Pin 1)

| # | From | To |
|---|---|----|
| P33-1 | Pi Pin 1 | DS3231 VCC |
| P33-2 | Pi Pin 1 | IR#1 VCC |
| P33-3 | Pi Pin 1 | IR#2 VCC |
| P33-4 | Pi Pin 1 | (opt) INMP441 VDD |

### +5 V Pi rail (red from Pin 2/4) — buzzer only

| # | From | To |
|---|---|----|
| P5-1 | Pi Pin 2 or 4 | Buzzer VCC |

### +5 V external rail (thick red)

| # | From | To |
|---|---|----|
| P5E-1 | External PSU +5 V | Servo 0…5 VCC (all six) |
| P5E-2 | External PSU +5 V | + of 1000 µF capacitor |
| P5E-3 | Capacitor − | GND bus |

### +3.7–4.2 V LiPo

| # | From | To |
|---|---|----|
| PL-1 | LiPo + | SIM800C VCC |
| PL-2 | LiPo + | + of 1000 µF at SIM (if fitted) |
| PL-3 | Capacitor − | GND bus |

### Signal wires

| # | From | Via | To |
|---|---|-----|----|
| S0 | Pi Pin 32 (GPIO 12) | 220–470 Ω (opt) | Servo 0 Signal |
| S1 | Pi Pin 33 (GPIO 13) | 220–470 Ω (opt) | Servo 1 Signal |
| S2 | Pi Pin 36 (GPIO 16) | 220–470 Ω (opt) | Servo 2 Signal |
| S3 | Pi Pin 11 (GPIO 17) | 220–470 Ω (opt) | Servo 3 Signal |
| S4 | Pi Pin 37 (GPIO 26) | 220–470 Ω (opt) | Servo 4 Signal |
| S5 | Pi Pin 13 (GPIO 27) | 220–470 Ω (opt) | Servo 5 Signal |
| IR1 | IR#1 OUT | — | Pi Pin 16 (GPIO 23) |
| IR2 | IR#2 OUT | — | Pi Pin 18 (GPIO 24) |
| BZ | Pi Pin 22 (GPIO 25) | — | Buzzer Signal |
| SDA | Pi Pin 3 (GPIO 2) | — | DS3231 SDA |
| SCL | Pi Pin 5 (GPIO 3) | — | DS3231 SCL |
| UTX | Pi Pin 8 (GPIO 14 TX) | — | SIM800C RX |
| URX | SIM800C TX | 10k/20k divider if needed | Pi Pin 10 (GPIO 15 RX) |
| CSI | Camera ribbon | — | Pi CSI port |

---

## 5. Block / schematic overview

```
                         ┌──────────────────────┐
   CSI Camera ───────────│   Raspberry Pi 5     │
                         │   USB-C ← 27W PD     │
                         └──┬────┬────┬────┬────┘
              3.3V / GND    │    │    │    │  UART GPIO14/15
         ┌──────────────────┘    │    │    └──────────────┐
         │                       │    │                   │
    ┌────┴────┐  ┌──────────┐   │   ┌┴────────┐   ┌──────┴───────┐
    │ DS3231  │  │ 2× FC-51 │   │   │ Buzzer  │   │   SIM800C    │
    │ I2C     │  │ GPIO23/24│   │   │ GPIO25  │   │ TX/RX + ant  │
    │ 0x68    │  │ 3.3V     │   │   │ VCC=5V  │   │ VCC←LiPo     │
    └─────────┘  └──────────┘   │   └─────────┘   └──────────────┘
                                │
                    PWM GPIO 12,13,16,17,26,27
                                │
                    ┌───────────┴───────────┐
                    │  6× MG996R (signal)   │
                    │  VCC ← External 5V    │
                    │  GND ← Common bus     │
                    └───────────────────────┘

  Mechanical (not wires): cylinder slots → drop hole → tube → IR#1 → tray → IR#2
```

---

## 6. Passive parts summary (resistors & capacitors)

| Qty | Part | Value | Where |
|----:|---|---|---|
| 1 | Electrolytic cap | 1000 µF / 16 V | External 5 V servo rail |
| 1 | Electrolytic cap | 1000 µF / 10 V | SIM800C VCC (if not onboard) |
| 0–6 | Series resistor | 220–470 Ω | Each servo PWM line (recommended) |
| 0–2 | Divider resistors | 10 kΩ + 20 kΩ | SIM800C TX → Pi RX **only if TX > 3.3 V** |
| 0–2 | I2C pull-ups | 4.7 kΩ | Only if DS3231 is bare IC (not module) |
| 0–1 | Pull-up | 10 kΩ | IR OUT only if open-collector clone |
| 0–1 | Base resistor + NPN | 1 kΩ + 2N2222 | Only if using bare buzzer (not module) |
| 1 | CR2032 | Coin cell | DS3231 backup |
| 1 | Terminal block | — | Common GND (+ optional 5 V bus) |

FC-51, DS3231 modules, and active buzzer modules already include their own
board-level resistors — you do not duplicate those on the breadboard.

---

## 7. Build order (recommended)

1. Fit CR2032 in DS3231; wire RTC to 3.3 V / GND / SDA / SCL only. Boot Pi, run `i2cdetect -y 1`.
2. Add both IR sensors; toggle beams and watch GPIO (or run hub in sim logs).
3. Add buzzer on GPIO 25 + 5 V.
4. Build **common GND** + external 5 V rail + one servo; test rotation; then add remaining five.
5. Fit CSI camera; `libcamera-hello -t 2000`.
6. Wire SIM800C last: LiPo + GND + UART (with divider if needed); antenna + SIM; test AT via `minicom` / hub SMS.
7. Optional INMP441 after voice is enabled in config.

---

## 8. Post-wiring checks

```bash
sudo i2cdetect -y 1          # expect 0x68
ls -l /dev/serial0           # SIM800C UART
libcamera-hello -t 2000      # camera
# Multimeter: all GNDs continuity; servo rail ~5.0 V; LiPo ~3.7–4.2 V
# Multimeter: SIM800C TX idle < 3.3 V before connecting to Pi RX
cd ~/pillsafe && source venv/bin/activate && python3 main.py
```

If servos jitter or the Pi reboots when a servo moves: external PSU current
is too low, GND not shared, or capacitor missing on the 5 V rail.

---

## 9. What is *not* electrical

- 6× rotating cylinders (9 slots), delivery tube, collection tray  
- Enclosure / mounting brackets  
These are mechanical only; they do not add nets to the circuit.

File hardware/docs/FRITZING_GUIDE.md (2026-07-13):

# PillSafe — Fritzing Circuit Guide

This document explains how to build the PillSafe hardware circuit in
**[Fritzing](https://fritzing.org/)** for your report, simulation planning, and
wiring verification. It matches `config.yaml` and the `hardware/` modules in
this repository.

**Companion files**

| File | Purpose |
|---|---|
| [`bom.csv`](bom.csv) | Bill of materials with quantities |
| [`fritzing_connections.csv`](fritzing_connections.csv) | Every net — import as a wiring checklist |

> Fritzing cannot run the full PillSafe Python stack (Picamera2, FaceNet, Flask).
> Use Fritzing for **schematic + breadboard documentation**; use `python main.py`
> on a PC for **software simulation** (GPIO modules auto-fallback when off-Pi).

---

## 1. Install Fritzing

1. Download from [https://fritzing.org/download/](https://fritzing.org/download/)
2. Open a new sketch: **File → New**
3. You will work in three views (tabs at the bottom):
   - **Breadboard** — physical layout
   - **Schematic** — logical wiring (best for thesis figures)
   - **PCB** — optional; only if you design a custom HAT/board

Save the sketch as `pillsafe_hardware.fzz` inside this `docs/` folder when done.

---

## 2. Parts to add from the Fritzing library

Search the **Parts** panel (right side) and drag each item onto the breadboard.

### Core (always add)

| Search in Fritzing | Qty | PillSafe role |
|---|-----|---|
| `Raspberry Pi 4` | 1 | Main controller |
| `Raspberry Pi Camera` | 1 | Face recognition (annotate “v2 / CSI”) |
| `servo` (generic hobby servo) | 6 | One per medication compartment |
| `Piezo Buzzer` or `Buzzer` | 1 | Active buzzer module (3.3 V) |
| `Power plug` or `Battery block` | 2 | Pi USB-C supply + external 5 V servo rail |
| `Ground` / `VCC` labels | several | Power annotation on schematic |

### Sensors & RTC

| Search in Fritzing | Qty | If not found |
|---|-----|---|
| `DS3231` or `RTC` | 1 | Use generic **I2C EEPROM** block and label pins SDA/SCL/VCC/GND |
| `IR` or `phototransistor` | 2 | Use **generic 3-pin breakout**; label “FC-51 drop” and “FC-51 pickup” |

### GSM & voice (annotate as external)

Fritzing often lacks SIM800L and INMP441. Use one of:

- **Generic breakout board** (4–6 pins) + text labels, or
- **Import custom part** from [Fritzing Fab library](https://fab.fritzing.org/) / SnapEDA

| Real part | Fritzing placeholder | Connection |
|---|---|---|
| SIM800L + USB-TTL | `USB connector` + labeled box “SIM800L” | USB to Pi; 3.7 V LiPo separate |
| INMP441 I2S mic | 5-pin breakout labeled “INMP441” | GPIO 18/19/20 + 3.3 V |

---

## 3. Recommended breadboard layout (zones)

Split the breadboard into zones so the diagram stays readable:

```
┌─────────────────────────────────────────────────────────────────┐
│  [A] Raspberry Pi 4B  +  CSI Camera (ribbon, off-board note)   │
├─────────────────────────────────────────────────────────────────┤
│  [B] DS3231 RTC (I2C)     [C] Buzzer        [D] INMP441 (opt.)  │
├─────────────────────────────────────────────────────────────────┤
│  [E] FC-51 IR #1 (drop)   [F] FC-51 IR #2 (pickup)              │
├─────────────────────────────────────────────────────────────────┤
│  [G] Servo 0 … Servo 5  (six servos in a row)                   │
├─────────────────────────────────────────────────────────────────┤
│  [H] External 5 V supply → servo VCC rail                       │
│  [I] GND bus (Pi GND + servo PSU GND + LiPo GND)                │
├─────────────────────────────────────────────────────────────────┤
│  [J] Off-board: SIM800L + LiPo + USB-TTL (dashed box + note)    │
└─────────────────────────────────────────────────────────────────┘
```

**Tip:** For a thesis diagram, draw **one servo** on the breadboard and add a note
“×6 compartments — GPIO 12, 13, 16, 17, 26, 27” to avoid clutter. Keep all six
on the schematic view using a duplicate-servo pattern.

---

## 4. Wire every connection (BCM = what the code uses)

All GPIO numbers below are **BCM**, not physical pin numbers.

### Power rails (draw first)

```
Pi 3.3V  ──► DS3231 VCC, both FC-51 VCC, Buzzer VCC, INMP441 VDD
External 5V ──► all 6× servo VCC (red)
Common GND ──► Pi GND, all servo GND, DS3231 GND, IR GND×2, Buzzer GND,
               INMP441 GND, external 5V GND, SIM800L GND, LiPo GND
LiPo 3.7V+ ──► SIM800L VCC only
```

### GPIO signals

| Signal | BCM GPIO | Physical pin | Device |
|---|---|---|---|
| Servo 0 PWM | 12 | 32 | Compartment 0 |
| Servo 1 PWM | 13 | 33 | Compartment 1 |
| Servo 2 PWM | 16 | 36 | Compartment 2 |
| Servo 3 PWM | 17 | 11 | Compartment 3 |
| Servo 4 PWM | 26 | 37 | Compartment 4 |
| Servo 5 PWM | 27 | 13 | Compartment 5 |
| IR drop OUT | 23 | 16 | FC-51 at chute |
| IR pickup OUT | 24 | 18 | FC-51 at base |
| Buzzer IN | 25 | 22 | Active buzzer |
| I2C SDA | 2 | 3 | DS3231 |
| I2C SCL | 3 | 5 | DS3231 |
| I2S BCLK | 18 | 12 | INMP441 SCK (optional) |
| I2S LRCLK | 19 | 35 | INMP441 WS (optional) |
| I2S DATA | 20 | 38 | INMP441 SD (optional) |

Full netlist: [`fritzing_connections.csv`](fritzing_connections.csv)

### Off-board connections (use dashed wires + notes in Fritzing)

| Link | Notes |
|---|---|
| Pi CSI ↔ Camera v2 | 15-pin ribbon — not on breadboard |
| Pi USB ↔ USB-TTL ↔ SIM800L | Serial at 9600 baud (`/dev/ttyUSB0`) |
| LiPo ↔ SIM800L | Separate power; **never** from Pi 3.3 V/5 V |

---

## 5. Schematic view — build order

1. Place **Raspberry Pi 4** symbol (or GPIO header symbol if Pi part is too large).
2. Add **DS3231** on I2C: SDA→GPIO2, SCL→GPIO3, 3.3 V, GND.
3. Add **two IR sensors** as digital inputs to GPIO 23 and 24; annotate:
   - GPIO 23: LOW = pill in chute
   - GPIO 24: HIGH = pill removed from base
4. Add **buzzer** on GPIO 25.
5. Add **six servos** with PWM inputs on GPIO 12, 13, 16, 17, 26, 27; VCC to
   external 5 V rail; GND to common GND.
6. Add **power symbols**: +3.3 V, +5 V (servo), +3.7 V (GSM), GND.
7. Optional: **INMP441** on GPIO 18/19/20.
8. Add **note boxes** for Camera (CSI) and SIM800L (USB + LiPo).

Use **schematic → Export → PDF/PNG** for your final-year report.

---

## 6. Colour convention (breadboard wires in Fritzing)

| Colour | Use |
|---|-----|
| Red | +3.3 V, +5 V servo, +3.7 V GSM |
| Black / brown | GND |
| Orange | Servo PWM signal |
| Yellow | IR sensor OUT |
| Green | Buzzer signal |
| Blue / purple | I2C SDA / SCL |

---

## 7. System block diagram (for Fritzing notes / report)

Paste this as a **Note** in Fritzing or into your report:

```
                    ┌──────────────────┐
   Pi Camera (CSI)──│  Raspberry Pi 4B │
   USB (GSM TTL)────│  Flask API       │
                    │  FaceNet + Voice │
                    └───┬──────────────┘
        GPIO          │ I2C      │ (optional I2S)
         │            │          │
    6× Servo      DS3231 RTC   INMP441
    2× FC-51 IR
    1× Buzzer

Mechanical (not electrical):
  6 cylinders (9 slots) → drop hole → tube → IR#1 → base → IR#2
  No gate servo — gravity dispense only
```

---

## 8. Two Fritzing sketches (recommended for clarity)

| Sketch | Contents | Use in report |
|---|---|---|
| **pillsafe_core.fzz** | Pi + RTC + 2× IR + buzzer + 1× servo example | “Control & sensing” figure |
| **pillsafe_power.fzz** | External 5 V rail, 6 servos, GND bus, LiPo + SIM800L | “Power distribution” figure |

---

## 9. Simulation limits in Fritzing

| What Fritzing can do | What it cannot do |
|---|---|
| Show correct wiring | Run `main.py` or Picamera2 |
| Export schematic/breadboard images | Simulate FaceNet or Flask API |
| Basic animation of nets | Model six mechanical cylinders |

**Software simulation (no hardware):** run on a PC — `hardware/*.py` uses
simulation mode when `RPi.GPIO` is missing (servos log `[SIM]`, IR always OK).

**Bench test jig (minimal hardware):** replace IR sensors with push-buttons to
GND (GPIO 23/24) and one servo on GPIO 12 before building all six compartments.

---

## 10. Export checklist for submission

- [ ] Breadboard view PNG (300 DPI)
- [ ] Schematic view PDF
- [ ] BOM table from [`bom.csv`](bom.csv)
- [ ] Pin table (Section 4) in report appendix
- [ ] Note: six servos on external 5 V, common GND
- [ ] Note: SIM800L on separate LiPo
- [ ] Note: no gate — rotation + gravity only

---

## 11. Verify wiring against the real Pi

After building physically, run on the Pi:

```bash
i2cdetect -y 1          # expect 0x68 (DS3231)
ls /dev/ttyUSB*         # GSM adapter
libcamera-hello -t 2000 # camera
python3 main.py         # full system
```

GPIO assignments must match `config.yaml` → `servo.pins`, `ir_sensors.*`,
`buzzer.pin`, and `hardware.i2s_mic.*`.

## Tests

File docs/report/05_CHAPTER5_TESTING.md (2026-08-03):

# Chapter 5 — Testing and Results

Word-ready body. Replace bracketed placeholders `[N]`, `[xx%]`, etc. with your measured campaign data. Keep the table structures even if some rows are marked “not yet measured” or “simulated GSM.”

---

## 5.1 Introduction

This chapter reports functional and performance tests of PillSafe against the project objectives: biometric access control, timed dispensing, reminder behaviour, missed-dose handling, and mobile schedule/monitoring features. Tests were run on the Raspberry Pi 5 hub with the React Native client unless noted. Where physical GSM or IR hardware was unavailable, those paths were exercised in simulation or with the dose-due test endpoint and logged as such.

---

## 5.2 Test environment

| Item | Configuration |
|---|---|
| Hub | Raspberry Pi 5, Raspberry Pi OS 64-bit |
| Config | `hardware/config.yaml` as deployed for the trial |
| Face model | MobileFaceNet TFLite + Haar cascade |
| Servo mode | Continuous; `angle_per_slot: 40`; calibrated `degrees_per_second` |
| App | React Native build / Expo Go as used in demo |
| Network | Pi hotspot or LAN; API token set |
| GSM | SIM800C live **or** logged AT simulation — state which |
| IR | `required: true/false` — state which for each table |

---

## 5.3 Facial verification

**Procedure:** Enrol one authorised user under controlled lighting. Run `[N]` verify attempts as the true user and `[N]` attempts with an impostor or unenrolled face. Record accept / reject and mean confidence where available.

**Table 5.1 — Face verification**

| Trial class | Attempts (N) | Accepted | Rejected | True accept / False reject rate | Notes |
|---|---|---|---|---|---|
| Genuine user | | | | TAR = ··· | |
| Impostor / unknown | | | | FAR = ··· | |
| Poor lighting / angle | | | | | Optional stress |

**Discussion:** Comment on threshold (`confidence_threshold` / `distance_threshold`), retry sets (`max_retries`, `reject_sets_before_sms`), and any lockouts observed.

*[Insert Figure 5.1 — bar chart of accept/reject]*

---

## 5.4 Voice verification (if claimed in objectives)

**Procedure:** Enrol voice for the same user. Run genuine and impostor (or wrong phrase) trials with the Voice HAT.

**Table 5.2 — Voice verification**

| Trial class | Attempts (N) | Accepted | Rejected | Rate | Notes (sample rate / noise) |
|---|---|---|---|---|---|
| Genuine | | | | | |
| Impostor / wrong phrase | | | | | |
| Face+voice combined policy | | | | | If both required |

If voice was disabled in the assessed build, state that clearly and mark Table 5.2 as deferred.

---

## 5.5 Dispense mechanics

**Procedure:** After successful verify (or dispenser unit test / dry-run), command one-slot advances. Measure time per step and visual/angular success (≈40°). Repeat across compartments if possible. With IR enabled, record drop/pickup detection.

**Table 5.3 — Slot advance**

| Compartment | Steps (N) | Correct ≈40° | Overshoot / undershoot | Mean time (s) | Failures |
|---|---|---|---|---|---|
| 1 (pin 12) | | | | | |
| 2 (pin 13) | | | | | |
| … | | | | | |
| Overall | | | | | |

**Table 5.4 — IR confirmation** (only if `ir_sensors.required` or sensors fitted)

| Event | Trials (N) | Detected | Missed | Detect rate |
|---|---|---|---|---|
| Pill drop (pin 23) | | | | |
| Pickup (pin 24) | | | | |

**Discussion:** Continuous open-loop drive depends on `degrees_per_second` and gear backlash; report calibration method and residual error.

---

## 5.6 Schedule → reminder → app alert latency

**Procedure:** Create a schedule shortly ahead of wall-clock time. Measure:

1. Hub recognition of dose-due (log / buzzer start).  
2. Buzzer audible within expected window (`dose_ready_duration_seconds`).  
3. App “Time Is Up” (or equivalent) appearance while the reminder poller runs.  
4. End-to-end latency from scheduled time to app alert.

**Table 5.5 — Reminder latency**

| Run | Scheduled time | Buzzer start Δt (s) | App alert Δt (s) | Verify Now reachable? |
|-----|---|---|---|---|
| 1 | | | | |
| 2 | | | | |
| 3 | | | | |
| Mean | | | | |

Use `POST /alerts/dose-due-test` for buzzer-only lab checks when schedule timing is inconvenient.

---

## 5.7 Missed-dose path

**Procedure:** Allow a due dose to expire past `grace_period_minutes` without successful verify. Confirm DB status **MISSED**, caregiver SMS (or simulated send log), and Monitor / Home missed counts.

**Table 5.6 — Missed-dose handling**

| Run | Grace (min) | MISSED in DB? | SMS sent / logged? | App Monitor count matches? |
|-----|---|---|---|---|
| 1 | 15 | | | |
| 2 | | | | |

Also note reject-set SMS after repeated failed verifies, if tested (`reject_sets_before_sms`).

---

## 5.8 Mobile application behaviour

**Table 5.7 — App functional checks**

| Feature | Pass/Fail | Notes |
|---|---|---|
| Connect with token + health | | |
| Create schedule (AM/PM) | | |
| Long-press edit schedule | | |
| Long-press delete schedule | | |
| Edit blocked after TAKEN today (if enforced) | | |
| Reminder → navigate to Verify | | |
| Verify disabled when no actionable dose | | |
| Monitor missed vs Home consistency | | |
| Camera preview (stream/snapshot) | | |

---

## 5.9 Limitations observed

Document honestly, for example:

1. **Continuous-servo calibration** — open-loop timing drifts with supply voltage, load, and print backlash; without an encoder, absolute slot index can drift over many cycles.  
2. **Background notifications** — when the app is fully backgrounded/killed, OS limits may prevent reminder polls; users should keep the app available during dose windows or rely on the hub buzzer + SMS.  
3. **Gear print tolerance** — FDM tooth geometry affects mesh and step consistency.  
4. **IR optional mode** — if `required: false`, TAKEN can be logged without physical confirmation (acceptable for bring-up, weaker for clinical claims).  
5. **GSM dependency** — SMS needs network, SIM credit, and correct UART level shifting.

---

## 5.10 Chapter summary

Summarise quantitative highlights once tables are filled (e.g. face TAR/FAR, dispense success rate, mean reminder latency, missed-path correctness). State which objectives were fully demonstrated versus partially demonstrated (e.g. voice deferred, IR simulated).

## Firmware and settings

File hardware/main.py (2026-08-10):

"""
PillSafe — Main Control Loop
Entry point that initialises all modules and coordinates the
dispensing workflow as described in the SDR §9.

Startup Sequence:
  1. Load configuration
  2. Initialise database
  3. Initialise hardware (camera, servo, IR sensors, buzzer, RTC, GSM)
  4. Load FaceNet (TFLite) recognition model
  5. Start Flask API server as a background thread
  6. Start the scheduling daemon
  7. Start the SMS alert service
  8. Enter idle state — wait for dispensing events

Operational Workflow (per event):
  1. Scheduler detects a time match → creates DispenseEvent
  2. REMINDER notification to the phone + dose-due buzzer (45–60 s)
  3. Camera activates → face detection + FaceNet (TFLite) verification
     (each Verify Now = up to 8 captures; SMS after 3 failed sets; lockout after 5)
  4. On ACCEPT: buzzer stops → servo rotates to slot → log TAKEN → SMS caregiver
  5. On REJECT lockout (5 failed sets): log REJECTED (caregiver already SMS'd at set 3)
  6. On TIMEOUT (grace period): log MISSED → SMS caregiver
  7. Return to idle (buzzer off; servo is not moved again)
"""

import os
import sys
import signal
import threading
import uuid
from datetime import datetime, timedelta

# Ensure project root is on the Python path
PROJECT_ROOT = os.path.dirname(os.path.abspath(__file__))
sys.path.insert(0, PROJECT_ROOT)
os.chdir(PROJECT_ROOT)

from utils.config import load_config, get_config
from utils.logger import setup_logger

# Load config first
load_config()
logger = setup_logger("pillsafe.main")

from database.db_manager import DatabaseManager
from core.camera import Camera
from core.detector import FaceDetector
from core.facenet_recogniser import FaceNetRecogniser
from core.decision import DecisionEngine, VerificationResult
from hardware.dispenser import Dispenser
from hardware.ir_sensor import IRSensorManager
from hardware.buzzer import Buzzer
from hardware.rtc import RealTimeClock
from hardware.gsm import GSMModule
from scheduler.schedule_controller import ScheduleController, DispenseEvent
from alerts.alert_service import AlertService
from enrollment.enrol_user import EnrolmentManager
from api.routes import create_app

try:
    from core.voice_recogniser import VoiceRecogniser
except Exception:  # pragma: no cover - optional when sounddevice/librosa missing
    VoiceRecogniser = None


class PillSafeSystem:
    """Main system controller — orchestrates all PillSafe components."""

    def __init__(self):
        logger.info("=" * 60)
        logger.info("PillSafe Smart Pill Dispenser — Starting Up")
        logger.info("=" * 60) 

        cfg = get_config()

        # ── Step 1: Database ─────────────────────────────────
        logger.info("Initialising database...")
        self.db = DatabaseManager()

        # ── Step 2: Hardware ─────────────────────────────────
        logger.info("Initialising hardware modules...")
        self.camera = Camera()
        self.rtc = RealTimeClock()
        self.dispenser = Dispenser()
        self.ir_sensors = IRSensorManager()
        self.buzzer = Buzzer()
        self.gsm = GSMModule()

        # ── Step 3: Core AI ──────────────────────────────────
        logger.info("Initialising facial recognition pipeline...")
        self.detector = FaceDetector()
        self.recogniser = FaceNetRecogniser()
        voice_cfg = getattr(cfg, "voice", None)
        voice_enabled = bool(voice_cfg and getattr(voice_cfg, "enabled", False))
        self.voice_recogniser = None
        if voice_enabled and VoiceRecogniser is not None:
            try:
                self.voice_recogniser = VoiceRecogniser()
                logger.info("Voice recogniser initialised")
            except Exception as e:
                logger.warning("Voice recogniser unavailable: %s — voice auth disabled", e)
        elif not voice_enabled:
            logger.info("Voice auth disabled in config (voice.enabled=false)")
        else:
            logger.warning("Voice dependencies missing — voice auth disabled")
        self.decision_engine = DecisionEngine(
            self.camera, self.detector, self.recogniser, self.voice_recogniser
        )

        # ── Step 4: Enrolment Manager ────────────────────────
        self.enrolment = EnrolmentManager(
            self.camera, self.detector, self.recogniser, self.db, self.voice_recogniser
        )

        # ── Step 5: Alert Service ────────────────────────────
        self.alert_service = AlertService(self.db, self.gsm)

        # ── Step 6: Scheduler ────────────────────────────────
        self.scheduler = ScheduleController(self.db, self.rtc)
        self.scheduler.set_event_callback(self._handle_dispense_event)

        # Active scheduler grace-window event (if any). Used so the app's
        # blocking Verify Now can hand off to the camera already waiting.
        self._active_dispense_event: DispenseEvent | None = None
        self._active_dispense_lock = threading.Lock()
        # Failed Verify Now sets per schedule (8 attempts each).
        # SMS caregiver at set 3; lockout at set 5.
        self._reject_sets: dict[int, int] = {}
        self._reject_sms_sent: set[int] = set()

        # ── Step 7: Flask API ────────────────────────────────
        self.app = create_app(
            db=self.db,
            enrolment_manager=self.enrolment,
            rtc=self.rtc,
            gsm=self.gsm,
            camera=self.camera,
            verify_dispense_fn=self.verify_and_dispense,
            dose_alert_fn=self.trigger_dose_due_alert,
        )

        self._running = False

    def start(self) -> None:
        """Start all background services and enter the main loop."""
        self._running = True

        # Register signal handlers for graceful shutdown
        signal.signal(signal.SIGINT, self._signal_handler)
        signal.signal(signal.SIGTERM, self._signal_handler)

        # Start the alert service
        self.alert_service.start()

        # Start the scheduler
        self.scheduler.start()

        # Start the Flask API in a background thread (FR-24)
        cfg = get_config()
        api_thread = threading.Thread(
            target=self.app.run,
            kwargs={
                "host": cfg.api.host,
                "port": cfg.api.port,
                "debug": False,
                "use_reloader": False,
            },
            daemon=True,
        )
        api_thread.start()
        logger.info("Flask API started on %s:%d", cfg.api.host, cfg.api.port)

        rtc_time = self.rtc.get_time_string("%Y-%m-%d %H:%M:%S")
        sys_time = datetime.now().strftime("%Y-%m-%d %H:%M:%S")
        logger.info("System ready — RTC time: %s | Pi time: %s", rtc_time, sys_time)
        try:
            skew = abs((self.rtc.get_time() - datetime.now()).total_seconds())
            if skew > 120:
                logger.warning(
                    "RTC is %.0f seconds off from the Pi clock. "
                    "Schedule matching uses RTC; keep them synced.",
                    skew,
                )
        except Exception:
            pass
        logger.info("Entering idle state — waiting for dispensing events...")

        # Keep the main thread alive
        try:
            while self._running:
                signal.pause()
        except AttributeError:
            # signal.pause() not available on Windows
            import time
            while self._running:
                time.sleep(1)

    def _handle_dispense_event(self, event: DispenseEvent) -> None:
        """
        Handle a dispensing event triggered by the scheduler.
        This runs in its own thread for each event.
        Implements the full operational workflow from SDR §9.
        """
        logger.info("=" * 40)
        logger.info("DISPENSING EVENT: %s for %s at %s",
                     event.medication_name, event.full_name, event.scheduled_time)
        logger.info("Compartment: %d | Grace deadline: %s",
                     event.compartment_index,
                     event.grace_deadline.strftime("%H:%M:%S"))
        logger.info("=" * 40)

        with self._active_dispense_lock:
            self._active_dispense_event = event

        # Step 1: Phone REMINDER first, then start the dose-due buzzer
        # (45–60 s, background). Buzzer must be stopped before dispensing.
        med_label = event.medication_name + (
            f" ({event.dosage})" if event.dosage else ""
        )
        self._notify(
            "REMINDER",
            f"Time is up to take your medicine: {med_label}",
            user_id=event.user_id,
        )
        self.buzzer.alert_dose_due()

        # Step 2: Activate camera (servo stays still until face is accepted)
        self.camera.start()

        cfg = get_config()
        dispense_cfg = getattr(cfg, "dispense", None)
        require_request = (
            getattr(dispense_cfg, "require_verify_request", True)
            if dispense_cfg is not None else True
        )

        try:
            if require_request:
                # App-initiated "Verify Now" handshake (FR-56/FR-57)
                self._run_verify_now_loop(event)
            else:
                # Autonomous timer-driven verification
                self._run_autonomous_verification(event)
        finally:
            # Do NOT stop the dose-due buzzer here — it must run its full
            # 45–60 s even if Verify Now is slow. Dispense stops it explicitly.
            self.camera.stop()
            dispense_cfg = getattr(get_config(), "dispense", None)
            if (
                dispense_cfg is not None
                and getattr(dispense_cfg, "home_after_dispense", False)
            ):
                self.dispenser.home(event.compartment_index)
            with self._active_dispense_lock:
                if self._active_dispense_event is event:
                    self._active_dispense_event = None
            self._reject_sets.pop(event.schedule_id, None)
            self._reject_sms_sent.discard(event.schedule_id)
            logger.info("Returning to idle state")

    def verify_and_dispense(
        self,
        user_id: int,
        schedule_id: int | None,
        auth_mode: str = "face",
        timeout_seconds: float = 90.0,
    ) -> dict:
        """
        App-triggered Verify Now: run face/voice auth, then dispense.

        If the scheduler is already in a grace window for this user/schedule,
        hand off to that loop (camera already running). Otherwise run an
        on-demand verification + dispense for late / missed / manual doses.
        """
        with self._active_dispense_lock:
            active = self._active_dispense_event

        if active is not None:
            if active.user_id != user_id:
                return {
                    "ok": False,
                    "http_status": 409,
                    "error": "Another patient's dose is awaiting verification",
                    "result": "BUSY",
                    "dispensed": False,
                }
            if schedule_id is not None and int(schedule_id) != active.schedule_id:
                return {
                    "ok": False,
                    "http_status": 409,
                    "error": "A different dose is currently awaiting verification on the hub",
                    "result": "BUSY",
                    "dispensed": False,
                }
            return self._handoff_to_active_event(
                user_id=user_id,
                schedule_id=active.schedule_id,
                auth_mode=auth_mode,
                timeout_seconds=timeout_seconds,
            )

        if schedule_id is None:
            return {
                "ok": False,
                "http_status": 400,
                "error": "schedule_id required when no dose is currently due on the hub",
                "result": "MISSING_SCHEDULE",
                "dispensed": False,
            }

        return self._on_demand_verify_dispense(
            user_id=user_id,
            schedule_id=int(schedule_id),
            auth_mode=auth_mode,
        )

    def _handoff_to_active_event(
        self,
        user_id: int,
        schedule_id: int,
        auth_mode: str,
        timeout_seconds: float,
    ) -> dict:
        """Queue PENDING_AUTH for the grace-window loop and wait for its result."""
        token = uuid.uuid4().hex
        result_event = threading.Event()
        result_holder: dict = {}
        self.app.config["PENDING_AUTH"] = {
            "user_id": user_id,
            "schedule_id": schedule_id,
            "mode": auth_mode,
            "token": token,
            "result_event": result_event,
            "result_holder": result_holder,
        }

        if not result_event.wait(timeout=timeout_seconds):
            pending = self.app.config.get("PENDING_AUTH") or {}
            if pending.get("token") == token:
                self.app.config["PENDING_AUTH"] = None
            return {
                "ok": False,
                "http_status": 504,
                "error": "Hub did not complete verification in time. Stand in front of the hub camera and try again.",
                "result": "TIMEOUT",
                "dispensed": False,
            }

        return {
            "ok": bool(result_holder.get("ok", False)),
            "http_status": 200 if result_holder.get("ok") else 401,
            "result": result_holder.get("result", "UNKNOWN"),
            "dispensed": bool(result_holder.get("dispensed", False)),
            "confidence": result_holder.get("confidence"),
            "auth_mode": result_holder.get("auth_mode", auth_mode),
            "medication_name": result_holder.get("medication_name"),
            "error": result_holder.get("error"),
        }

    def _publish_verify_result(self, pending: dict | None, payload: dict) -> None:
        """Signal a blocking /dispense/verify caller (if any)."""
        if not pending:
            return
        holder = pending.get("result_holder")
        event = pending.get("result_event")
        if isinstance(holder, dict):
            holder.clear()
            holder.update(payload)
        if event is not None:
            try:
                event.set()
            except Exception:
                pass

    def _on_demand_verify_dispense(
        self, user_id: int, schedule_id: int, auth_mode: str,
    ) -> dict:
        """Start the hub camera, verify identity, then dispense for a schedule."""
        sched = self.db.get_schedule_with_user(schedule_id)
        if not sched or int(sched["user_id"]) != int(user_id):
            return {
                "ok": False,
                "http_status": 404,
                "error": "Schedule not found for this user",
                "result": "NOT_FOUND",
                "dispensed": False,
            }
        if not sched.get("is_active", 1):
            return {
                "ok": False,
                "http_status": 400,
                "error": "Schedule is inactive",
                "result": "INACTIVE",
                "dispensed": False,
            }

        user = self.db.get_user(user_id)
        if auth_mode == "face" and user and not user.get("enrolment_status"):
            return {
                "ok": False,
                "http_status": 400,
                "error": "Face enrolment required before verification",
                "result": "MODEL_NOT_READY",
                "dispensed": False,
            }

        event = DispenseEvent(
            user_id=int(sched["user_id"]),
            full_name=sched.get("full_name") or "Patient",
            medication_name=sched["medication_name"],
            compartment_index=int(sched["compartment_index"]),
            schedule_id=int(sched["schedule_id"]),
            scheduled_time=sched["dose_time"],
            grace_deadline=datetime.now() + timedelta(minutes=1),
            slot_index=int(sched.get("slot_index") or 0),
            dosage=sched.get("dosage"),
            pills_per_dose=int(sched.get("pills_per_dose") or 1),
        )

        with self._active_dispense_lock:
            if self._active_dispense_event is not None:
                return {
                    "ok": False,
                    "http_status": 409,
                    "error": "Hub is busy with another dispense event",
                    "result": "BUSY",
                    "dispensed": False,
                }
            self._active_dispense_event = event

        self.camera.start()
        try:
            logger.info(
                "On-demand Verify Now: user %d schedule %d mode=%s",
                user_id, schedule_id, auth_mode,
            )
            outcome = self.decision_engine.run_verification(
                expected_user_id=event.user_id,
                auth_mode=auth_mode,
            )
            if outcome.result == VerificationResult.REJECTED:
                handled = self._handle_reject_set(event, auth_mode, outcome)
                return {
                    "ok": False,
                    "http_status": 401,
                    "result": VerificationResult.REJECTED.value,
                    "dispensed": False,
                    "confidence": outcome.confidence,
                    "auth_mode": auth_mode,
                    "medication_name": event.medication_name,
                    "error": handled.get("error"),
                }
            return self._finalize_verify_outcome(event, auth_mode, outcome)
        finally:
            self.camera.stop()
            dispense_cfg = getattr(get_config(), "dispense", None)
            if (
                dispense_cfg is not None
                and getattr(dispense_cfg, "home_after_dispense", False)
            ):
                try:
                    self.dispenser.home(event.compartment_index)
                except Exception as e:
                    logger.error("Failed to home dispenser after on-demand verify: %s", e)
            with self._active_dispense_lock:
                if self._active_dispense_event is event:
                    self._active_dispense_event = None

    def _finalize_verify_outcome(
        self, event: DispenseEvent, auth_mode: str, outcome,
    ) -> dict:
        """Map a VerificationOutcome to API payload and side effects."""
        result_name = (
            outcome.result.value
            if hasattr(outcome.result, "value")
            else str(outcome.result)
        )
        base = {
            "result": result_name,
            "confidence": outcome.confidence,
            "auth_mode": auth_mode,
            "medication_name": event.medication_name,
            "schedule_id": event.schedule_id,
        }

        if outcome.result == VerificationResult.ACCEPTED:
            dispensed = self._perform_dispense(event, auth_mode=auth_mode)
            return {
                **base,
                "ok": True,
                "http_status": 200,
                "dispensed": dispensed,
                "error": None if dispensed else "Verified but dispensing failed",
            }

        if outcome.result == VerificationResult.REJECTED:
            self._log_and_alert_rejected(event, auth_mode=auth_mode, send_sms=False)
            return {
                **base,
                "ok": False,
                "http_status": 401,
                "dispensed": False,
                "error": (
                    "Face did not match after 5 verification sets — "
                    "dispensing locked"
                ),
            }

        if outcome.result == VerificationResult.NO_FACE:
            return {
                **base,
                "ok": False,
                "http_status": 400,
                "dispensed": False,
                "error": "No face detected — stand in front of the hub camera and try again",
            }

        if outcome.result == VerificationResult.MODEL_NOT_READY:
            return {
                **base,
                "ok": False,
                "http_status": 400,
                "dispensed": False,
                "error": "Face model not ready — complete face enrolment first",
            }

        return {
            **base,
            "ok": False,
            "http_status": 400,
            "dispensed": False,
            "error": f"Verification incomplete ({result_name})",
        }

    # ── Verification strategies ──────────────────────────────

    def _run_autonomous_verification(self, event: DispenseEvent) -> None:
        """Timer-driven path: verify immediately when the dose is due."""
        pending = self.app.config.get("PENDING_AUTH") or {}
        auth_mode = pending.get("mode", "face")

        outcome = self.decision_engine.run_verification(
            expected_user_id=event.user_id,
            auth_mode=auth_mode,
        )

        if outcome.result == VerificationResult.ACCEPTED:
            logger.info("User %d verified — dispensing medication", event.user_id)
            self._perform_dispense(event, auth_mode=auth_mode)
        elif outcome.result == VerificationResult.REJECTED:
            self._log_and_alert_rejected(event, auth_mode=auth_mode)
        elif outcome.result == VerificationResult.NO_FACE:
            logger.info("No face detected — waiting for grace period to expire")
            self._wait_for_grace_period(event)
        else:
            logger.error("Verification returned: %s", outcome.result)
            self._wait_for_grace_period(event)

    def _run_verify_now_loop(self, event: DispenseEvent) -> None:
        """
        Wait for the mobile app to send a "Verify Now" request
        (POST /dispense/request or /dispense/verify), then authenticate
        in the chosen mode. Caregiver SMS after 3 failed sets; lockout after 5.
        Exits on success, lockout, or when the grace deadline is reached (FR-16).
        """
        import time
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

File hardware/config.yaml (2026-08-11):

# ============================================================
# PillSafe — Central Configuration File
# All tuneable system parameters in one place (NFR-21)
# ============================================================

# --- Facial Recognition (MobileFaceNet TFLite) ---
face:
  confidence_threshold: 60          # Minimum confidence (0–100) to accept a match
  distance_threshold: 0.4           # Max cosine distance (= 1 − confidence/100 at threshold 60)
  max_retries: 8                   # Face captures per Verify Now set
  reject_sets_before_sms: 3         # Caregiver SMS after this many failed sets
  reject_sets_before_lockout: 5     # Dispense lockout after this many failed sets
  sample_count: 30
  image_size: [112, 112]            # MobileFaceNet input size (H, W)
  cascade_path: "haarcascade_frontalface_default.xml"
  scale_factor: 1.1        # Smaller = more thorough scan (slower)
  min_neighbors: 3         # Lower = more detections, more false positives
  min_face_size: [50, 50]  # Minimum face size in pixels (W, H)
  dataset_path: "data/dataset"
  model_path: "data/models/mobilefacenet.tflite"

# --- Scheduling & Dispensing ---
schedule:
  grace_period_minutes: 15
  poll_interval_seconds: 15

# --- Dispensing handshake ---
# When require_verify_request is true the device waits for the mobile app's
# "Verify Now" (POST /dispense/request) before authenticating; set false for
# fully autonomous timer-driven verification at the scheduled time.
dispense:
  require_verify_request: true
  verify_request_poll_seconds: 2
  reminder_buzz_seconds: 30         # Re-buzz while waiting for Verify Now
  home_after_dispense: false        # Do not home the cylinder after a dose

# --- Servo Motors (one rotating cylinder per compartment) ---
# After successful face verification the servo rotates in 40° steps to the
# scheduled slot (9 slots × 40° = 360°). Stays still until verification succeeds.
servo:
  frequency_hz: 50
  num_compartments: 6
  num_slots: 9
  angle_per_slot: 40                 # compartment (ring) degrees per dose slot
  dispense_slots: 1                  # each verify advances exactly one slot (40° ring)
  # Gear train: servo pinion drives compartment ring.
  # θ_servo = θ_compartment × (compartment_teeth / pinion_teeth)
  # One 40° slot → 40 × (135/17) ≈ 317.65° at the servo shaft.
  pinion_teeth: 17
  compartment_teeth: 135
  # continuous = timed steps with gear ratio (360° / continuous-rotation MG996R)
  # positional = absolute/relative PWM (true 0–180° position servos only)
  mode: continuous
  pins: [12, 13, 22, 17, 26, 27]
  # Continuous-rotation calibration — degrees_per_second is SERVO shaft speed.
  # Duration for one slot ≈ (40 × 135/17) / degrees_per_second.
  # Leave slot_pulse_seconds unset (null) to use gear math; set it only to override.
  neutral_duty: 7.5                  # stop (≈ 1.5 ms pulse at 50 Hz)
  run_duty_offset: 1.5               # keep modest; large values slam positional units
  degrees_per_second: 200            # servo °/s while running; tune live
  slot_pulse_seconds: null           # null = use gear ratio; or e.g. 1.59 to force
  settle_time: 0.15
  # Positional-only settings (ignored in continuous mode)
  travel_degrees: 180
  min_duty: 2.5
  max_duty: 12.5
  hold_time: 0.8
  use_slot_indexing: true
  max_angle: 360                     # legacy; continuous mode uses angle_per_slot

# --- IR Sensors ---
# When required is false, a successful verify + servo move logs TAKEN even if
# the IR sensors do not confirm drop/pickup (common during hardware bring-up).
ir_sensors:
  pill_detect_pin: 23
  pill_pickup_pin: 24
  debounce_ms: 200
  required: false

# --- Buzzer ---
# Sounds only when a scheduled dose becomes due (not during dispensing).
buzzer:
  pin: 25
  active_low: false                 # set true if your module buzzes when pin is LOW
  dose_ready_duration_seconds: 50   # alert length (clamped to 45–60 s)
  dose_ready_beep_seconds: 0.4      # on time per beep
  dose_ready_gap_seconds: 0.6       # off time between beeps
  # Kept for older configs; ignored by the new long dose-due alert.
  dose_ready_pattern: [0.2, 0.1, 0.2, 0.1, 0.2]
  success_pattern: [0.5]
  failure_pattern: [0.1, 0.1, 0.1, 0.1, 0.1]
  missed_pattern: [1.0, 0.5, 1.0]
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

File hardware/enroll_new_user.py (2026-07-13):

#!/usr/bin/env python
"""
PillSafe — Standalone User Enrolment Tool
==========================================
Enrol one or more users with a live camera preview.

For each user this script:
  1. Creates the database record (name, caregiver phone, compartment).
  2. Captures face samples with a live preview window (bounding box +
     progress bar) into  data/dataset/<user_id>/ .
  3. Trains the MobileFaceNet embeddings  ->  data/dataset/<user_id>/embeddings.npy .
  4. Marks the user as enrolled in the database.

Usage:
    python enroll_new_user.py

Controls during capture:
    q  — abort the current capture
"""

import os
import sys
import time

import cv2

# Resolve relative paths (data/models, data/dataset, …) from this package,
# regardless of the shell's working directory.
PROJECT_ROOT = os.path.dirname(os.path.abspath(__file__))
sys.path.insert(0, PROJECT_ROOT)
os.chdir(PROJECT_ROOT)

from utils.config import load_config, get_config
from utils.logger import setup_logger
from core.camera import Camera
from core.detector import FaceDetector
from core.facenet_recogniser import FaceNetRecogniser
from database.db_manager import DatabaseManager

try:
    from core.voice_recogniser import VoiceRecogniser
except Exception:  # pragma: no cover - voice auth is optional when audio deps are missing
    VoiceRecogniser = None

logger = setup_logger("pillsafe.enroll")

WINDOW_NAME = "PillSafe Enrolment — press 'q' to abort"
VOICE_PROMPTS = [
    "open my medicine",
    "dispense my pills",
    "pillsafe unlock",
]


# ──────────────────────────────────────────────────────────────────
# Live preview overlay
# ──────────────────────────────────────────────────────────────────
def draw_overlay(frame, name, captured, total, bbox=None, face_ok=False):
    """Return a copy of `frame` with enrolment overlays drawn on it."""
    disp = frame.copy()
    h, w = disp.shape[:2]

    # Top banner
    top = disp.copy()
    cv2.rectangle(top, (0, 0), (w, 70), (0, 0, 0), -1)
    cv2.addWeighted(top, 0.6, disp, 0.4, 0, disp)
    cv2.putText(disp, "ENROLLMENT", (15, 28),
                cv2.FONT_HERSHEY_SIMPLEX, 0.8, (0, 165, 255), 2)
    cv2.putText(disp, f"User: {name}", (15, 55),
                cv2.FONT_HERSHEY_SIMPLEX, 0.6, (255, 255, 255), 1)

    # Face bounding box
    if bbox is not None:
        x, y, bw, bh = bbox
        colour = (0, 255, 0) if face_ok else (0, 200, 255)
        cv2.rectangle(disp, (x, y), (x + bw, y + bh), colour, 2)

    # Progress bar
    bar_x, bar_y, bar_w = 15, h - 40, w - 30
    pct = captured / total if total else 0
    cv2.rectangle(disp, (bar_x, bar_y), (bar_x + bar_w, bar_y + 22),
                  (80, 80, 80), -1)
    cv2.rectangle(disp, (bar_x, bar_y), (bar_x + int(bar_w * pct), bar_y + 22),
                  (0, 255, 0), -1)
    cv2.putText(disp, f"Samples: {captured}/{total}", (bar_x + 8, bar_y + 17),
                cv2.FONT_HERSHEY_SIMPLEX, 0.55, (255, 255, 255), 1)

    # Hint
    hint = "Face detected - hold steady, vary angle slightly" if face_ok \
        else "Position your face in the frame..."
    cv2.putText(disp, hint, (15, h - 55),
                cv2.FONT_HERSHEY_SIMPLEX, 0.5, (0, 255, 255), 1)

    return disp


# ──────────────────────────────────────────────────────────────────
# Sample capture with live preview
# ──────────────────────────────────────────────────────────────────
def capture_samples(camera, detector, user_id, name, sample_count, dataset_path):
    """
    Capture `sample_count` face samples with a live preview.
    Returns the number of samples actually captured (0 if aborted).
    """
    user_dir = os.path.join(dataset_path, str(user_id))
    os.makedirs(user_dir, exist_ok=True)

    # Clear any existing samples (supports clean re-enrolment)
    for f in os.listdir(user_dir):
        try:
            os.remove(os.path.join(user_dir, f))
        except OSError:
            pass

    print(f"\nCapturing {sample_count} samples for '{name}'.")
    print("A preview window will open. Look at the camera and vary your")
    print("head angle slightly. Press 'q' in the window to abort.\n")

    captured = 0
    last_save = 0.0
    max_attempts = sample_count * 30
    attempts = 0

    while captured < sample_count and attempts < max_attempts:
        attempts += 1
        frame = camera.capture_frame()
        if frame is None:
            time.sleep(0.05)
            continue

        detections = detector.detect_and_extract(frame)
        bbox = None
        face_ok = len(detections) > 0

        if face_ok:
            # Use the largest detected face
            roi, bbox = max(detections, key=lambda d: d[1][2] * d[1][3])

            # Throttle saves so samples capture some variation (~0.25s apart)
            now = time.time()
            if now - last_save >= 0.25:
                img_path = os.path.join(user_dir, f"face_{captured:03d}.jpg")
                cv2.imwrite(img_path, roi)
                captured += 1
                last_save = now
                logger.info("Captured sample %d/%d for user %d",
                            captured, sample_count, user_id)

        disp = draw_overlay(frame, name, captured, sample_count, bbox, face_ok)
        cv2.imshow(WINDOW_NAME, disp)

        if (cv2.waitKey(1) & 0xFF) == ord('q'):
            print("Capture aborted by user.")
            break

    cv2.destroyWindow(WINDOW_NAME)
    cv2.waitKey(1)  # flush the window-close event on some platforms
    return captured
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

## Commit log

2026-07-13 Add Pi hardware hub and wire the mobile app to the live Flask API.
    Includes face/voice verification tooling with silence rejection, Device Connection settings, and demo docs; excludes local biometrics, DBs, and model binaries.
    [bom.csv, fritzing_connections.csv]
2026-07-15 Fix hub integrity gaps and wire remaining mobile screens to the live Pi API.
    Honours NO_FACE/pickup IR/voice soft-import on the hub, and replaces mock enrol/add-med/monitor flows with real API calls while ignoring local biometric artifacts.
    [config.yaml]
2026-07-16 Align hub hardware with Raspberry Pi 5 and SIM800C UART alerts.
    Switch GPIO to lgpio with RPi.GPIO/sim fallbacks, update MG996R/5V buzzer settings, and default voice off for Phase 1 face-first demo.
    [bom.csv]
2026-07-16 Add complete Pi 5 wiring guide for the hardware hub.
    Document the full circuit, power domains, and optional protection parts so the build matches the updated SIM800C and MG996R wiring.
    [bom.csv, fritzing_connections.csv]
2026-07-17 Improve app auth flow, profile, and multi-dose verification.
    Sign in before hub connection, allow skipping voice on PC, add profile/delete account, and stop missed doses from blocking later verifies.
2026-07-20 Fix Verify Now to wait for hub face auth before dispense.
    Make today's schedule rows open Verify, and return real match results from POST /dispense/verify.
    [main.py]
2026-07-20 Fix dose flow: slot angles, TAKEN status, and caregiver SMS rules.
    Dispense at slot×40° only after face match, buzz and notify at dose time, SMS at 3 fails / lock at 5, and SMS on taken or missed.
    [config.yaml, dispenser.py, gsm.py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]
2026-07-30 Changes for Camera live streaming, added expo pillsafe app
    Changes for Camera live streaming, added expo pillsafe app
    [PillSafe_Design.blend, PillSafe_Design_SIZED.blend, Updated compartment.stl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]
2026-07-30 Button change
2026-07-30 blender
    Changes
    [Updated compartment.stl, Updated pillsafe base.stl, Updated servo gear.stl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]
2026-07-30 Update servo pin configuration in config.yaml
2026-07-31 Enhance voice recognition configuration and improve device selection logic for audio input
2026-07-31 Add camera snapshot endpoint and update CameraPreview component for live feed
2026-07-31 Refactor medication reminder system and enhance time selection UI
    - Updated the PillSafeSystem to notify users with a single buzzer sound when a dose is due, removing repetitive reminders.
    - Removed unnecessary buzzer sounds for various states (success, failure, missed) to streamline user experience.
    - Enhanced AddMedicationScreen to allow users to select dose time using a more intuitive hour, minute, and AM/PM picker instead of a text input.
    - Implemented formatTime12h and toDoseTime24h utility functions for better time formatting and conversion.
    - Updated HomeScreen, ScheduleScreen, and VerifyScreen to display times in a user-friendly 12-hour format.
    - Added visual feedback for buttons bas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
    [main.py]
2026-07-31 Enhance buzzer functionality and reminder notifications
    - Updated the buzzer configuration to support a dose-due alert lasting 45–60 seconds, ensuring it only sounds during reminders and not during dispensing.
    - Modified the PillSafeSystem to prioritize phone notifications before activating the buzzer for dose reminders.
    - Improved the buzzer's alert mechanism to allow for background operation while accepting user interactions.
    - Adjusted reminder polling frequency to 3 seconds for more timely notifications on medication due times.
    - Enhanced alert messages for clarity and user engagement.
    [buzzer.py, config.yaml, main.py]
2026-07-31 Enhance dose alert functionality and improve logging
    - Added a new method to trigger dose due alerts manually, allowing for testing without waiting for the schedule.
    - Updated the buzzer configuration to improve alert timing and added support for active low configuration.
    - Enhanced logging to provide clearer information about system readiness and RTC clock skew.
    - Adjusted reminder polling frequency to 2.5 seconds for more timely notifications.
    - Improved error handling and logging in the reminder polling process.
    [buzzer.py, config.yaml, main.py]
2026-07-31 Refactor dispenser configuration and enhance servo control logic
    - Updated the servo configuration in config.yaml to include angle_per_slot, mode, and continuous-rotation settings for improved clarity and functionality.
    - Refactored the Dispenser class in dispenser.py to accommodate new servo parameters and enhance continuous rotation handling.
    - Added methods for calculating shortest slot deltas and improved duty cycle mapping for positional servos.
    - Updated unit tests to reflect changes in dispenser logic and ensure accurate angle and duty cycle calculations.
    [config.yaml, dispenser.py]
2026-08-03 new change
    [Compartment updated.stl, PillSafe_Design_SIZED.blend, PillSafe_Design_SIZED_copy.blend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]
2026-08-03 servo maths
2026-08-10 Add Africa's Talking SMS integration with configuration and sending functionality
    - Created africasTalking.js for storing credentials and configuration settings.
    - Implemented sendAfricasTalkingSms function in africasTalkingSms.js for sending SMS via Africa's Talking API.
    - Added form encoding utility for preparing request payloads.
    - Included error handling for API responses and validation for required fields.
    [PillSafe_Design_SIZED_copy.blend, PillSafe_Design_SIZED_copy_BACKUP_20260801_173003.blend, PillSafe_Design_SIZED_copy_BACKUP_20260801_185550.blend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]
2026-08-10 Refactor SMS alert system to prioritize Africa's Talking for caregiver notifications
    - Updated the alert service to use Africa's Talking as the primary SMS channel, with GSM as a secondary option and a phone fallback for PENDING_PHONE_SMS notifications.
    - Enhanced configuration in `config.yaml` to include live credentials for Africa's Talking.
    - Improved documentation in README and demo files to reflect the new SMS flow and setup requirements.
    - Adjusted error handling and logging for SMS delivery attempts across different channels.
    [config.yaml, gsm.py]
2026-08-10 feat: Add network management features for hotspot and Wi-Fi connections
    - Implemented API endpoints for getting network status, enabling hotspot, and joining Wi-Fi.
    - Updated configuration to include network mode and default hotspot settings.
    - Enhanced DeviceConnectionScreen to manage network modes and handle Wi-Fi connections.
    - Introduced network_manager.py to control Wi-Fi and hotspot functionalities using NetworkManager.
    - Added deployment scripts for setting up the service on Raspberry Pi, including sudoers configuration for nmcli.
2026-08-10 fix: Prevent MG996R servos from creeping by setting idle PWM to 0% after neutral arm
    [dispenser.py]
2026-08-11 fix: Update sample_count in hardware configuration from 50 to 30 for improved performance
    [config.yaml]
2026-08-12 feat: implement caregiver phone input component and integrate into signup and settings screens
    - Added CaregiverPhoneInput component for selecting country and entering national phone number.
    - Updated SignUpScreen to use CaregiverPhoneInput for caregiver phone entry with validation.
    - Refactored DeviceConnectionScreen and SettingsDetailScreen to utilize KeyboardScreen for better keyboard handling.
    - Enhanced phone number validation logic in utils/phoneCountries.js.
    - Improved navigation reset logic on sign out in ProfileScreen and SettingsScreen.
    - Introduced KeyboardScreen component for consistent keyboard avoidance across screens.
2026-08-12 feat: add support for auto-starting Expo Metro on Raspberry Pi boot
